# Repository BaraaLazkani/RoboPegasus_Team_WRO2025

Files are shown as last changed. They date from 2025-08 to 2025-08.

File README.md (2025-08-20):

## <center>RoboPegasus Team Report for WRO Future Engineers Category (2025)</center>
<p align="center">
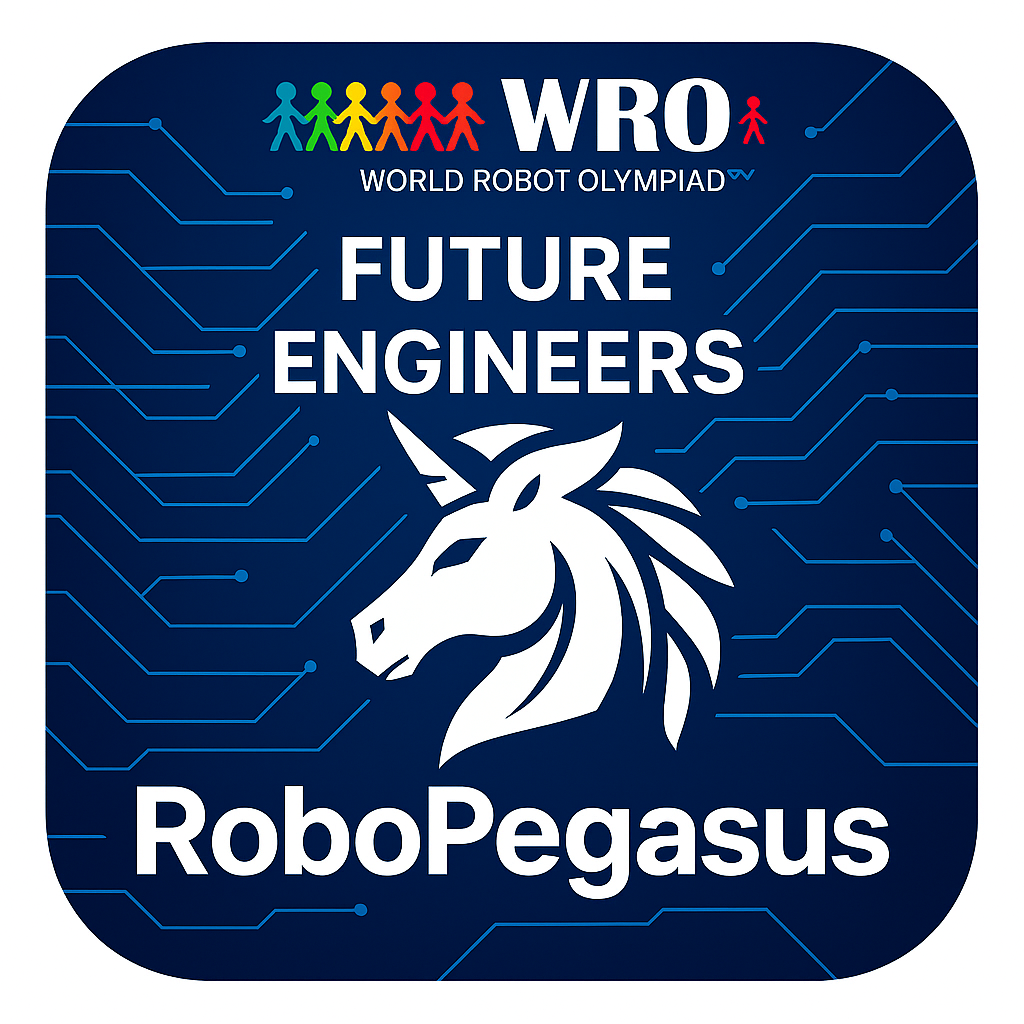
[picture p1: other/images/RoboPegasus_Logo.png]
WRO Logo
  
</p>

<p align="center">
  <strong>🏆 WRO Future Engineers 2025 Competition Entry</strong><br>
  Advanced Autonomous Navigation Robot
</p>

---

# 📋 Table of Contents

## 🚀 [Getting Started](#quick-start)
- [Repository Access & Requirements](#repository-access)
- [Video Demonstrations](#video-demonstrations)
- [Key Features Overview](#key-features)

## 📁 [Project Structure](#repository-structure)
- [Repository Organization](#file-organization)
- [Content Overview](#content-overview)

## 🔧 [Technical Documentation](#technical-documentation)

### ⚙️ [Robot Mechanisms](#robot-mechanisms)
- [Differential Gears](#differential-gears)
  - [Types of Differentials](#types-of-differentials)
  - [Benefits of Differential Gears](#benefits-of-differential-gears)
- [Ackermann Steering](#ackermann-steering)
  - [How It Works](#how-it-works)
  - [Main Purpose](#main-purpose)
- [Mechanism Integration](#fusion-between-differential-gears-and-ackermann-steering)
  - [Experiments Conducted](#experiments-conducted)
- [Implementation Details](#mechanisms-implementaion)
  - [Open Differential Implementation](#open-differential-implementation)
  - [Back Plexi Component](#1-back-plexi-component)
  - [Differential Replica](#2-differential-replica)
  - [Axis Component](#3-axis-component)
  - [Axis Holder](#4-axis-holder)
  - [Differential Holder](#5-differential-holder)
  - [Motor Holder](#6-motor-holder)
  - [Final Assembly](#6-final-assembly)
- [Ackermann Steering Implementation](#ackermann-steering-implementation)
  - [Original Kit Limitations](#original-kit-limitations-and-design-constraints)
  - [Custom Design Solution](#custom-plexi-glass-plate-design-and-manufacturing)
  - [Manufacturing Process](#manufacturing-process-and-quality-control)
  - [Performance Validation](#integration-benefits-and-performance-validation)

### 🚗 [Vehicle Design](#vehicle-main-body)
- [Main Body Design](#vehicle-main-body)
  - [Design Philosophy](#complete-from-scratch-design-philosophy)
  - [Manufacturing Techniques](#advanced-manufacturing-techniques)
  - [Precision Engineering](#precision-engineering-the-differential-challenge)
  - [Steering Integration](#ackermann-steering-integration)
- [Design Evolution](#evolution-through-iteration-learning-from-the-first-prototype)
  - [First Prototype Challenges](#first-prototype---design-challenges)
  - [Second Generation](#the-perfected-second-generation)
  - [Structural Redesign](#complete-structural-redesign)
  - [Power Management Revolution](#revolutionary-power-management-system)
- [Virtual Robot](#virtual-robot)
  - [CAD Modeling](#cad-design-and-modeling-philosophy)
  - [System Visualization](#complete-system-visualization)
  - [Architecture Design](#multi-tiered-architecture-design)
  - [Engineering Validation](#engineering-validation-through-virtual-modeling)
- [Design Lessons](#robots-design-lessons)

### 🏃 [Mobility Management](#mobility-management)
- [Motor Selection](#motor-selection-and-implementation)
  - [Drive Motor Specifications](#primary-drive-motor-jga25-370-245-rpm-dc-motor)
  - [Steering Actuator](#steering-actuator-mg996r-servo-motor)
  - [Control Implementation](#motor-control-implementation)
- [Chassis Design](#chassis-design-and-structural-implementation)
  - [Material Selection](#material-selection-and-structural-philosophy)
  - [Multi-Level Configuration](#multi-level-chassis-configuration)
  - [Component Integration](#component-integration-and-mounting-strategy)
- [Performance Analysis](#engineering-principles-and-performance-analysis)

### ⚡ [Power and Sense Management](#power-and-sense-management)
- [Battery System](#battery-specifications-and-power-analysis)
  - [Primary Power Source](#primary-power-source-zeee-li-poly-battery)
  - [Power Analysis](#power-consumption-analysis-and-runtime-calculations)
  - [Runtime Calculations](#component-power-consumption-summary)
- [Power Management System](#power-management-system-pms)
  - [Distribution Architecture](#custom-power-distribution-architecture)
  - [Star Topology](#star-topology-power-distribution)
- [Sensor Systems](#sensor-integration-and-selection-rationale)
  - [Ultrasonic Array](#ultrasonic-sensor-array-hc-sr04)
  - [Dynamic Positioning](#dynamic-sensor-positioning-sg90-servo-motors)
  - [Inertial Measurement](#inertial-measurement-mpu6050-imu)
  - [Infrared Detection](#infrared-detection-ir-sensor)
- [Processing Systems](#primary-processing-systems)
  - [Arduino Mega Implementation](#arduino-mega-2560-sensor-interface-and-control)
  - [Raspberry Pi Setup](#raspberry-pi-5-computer-vision-processing)

### 🚧 [Obstacle Management](#obstacle-management)
- [Open Challenge Algorithm](#autonomous-robot-navigation-algorithm-for-open-challenge)
  - [Algorithm Flow](#algorithm-flow)
  - [Algorithm Structure](#algorithm-structure)
  - [Control Parameters](#control-parameters)
  - [Mission Completion](#mission-completion-criteria)
- [Obstacle Challenge System](#obstacle-challenge-navigation-system)
  - [Startup Protocol](#startup-from-the-parking-lot)
  - [Directional Determination](#directional-determination-algorithm)
  - [CCW Navigation](#counter-clockwise-ccw-navigation-mode)
  - [CW Navigation](#clockwise-cw-navigation-mode)
  - [Corner Positioning](#corner-positioning-protocol)
  - [Pillar Navigation](#navigation-through-pillars)
- [Computer Vision](#pillar-color-detection-methodology)
  - [Detection Algorithm](#color-detection-algorithm)
  - [Pillar Classification](#pillar-configuration-classification)
  - [Error Handling](#error-handling-and-edge-cases)

## 👥 [Project Information](#project-information)
- [Team Contact](#team-contact)
  - [Team Members](#team-members)
  - [Contact Information](#contact-information)

---

## Quick Start

### Repository Access
**Important Note:** If accessing this GitHub repository from a restricted area, a VPN must be used for proper content display and functionality.

### Video Demonstrations
- **Open Challenge:** [Watch on YouTube (Coming Soon)](https://youtu.be/jW7eVu1ZF-4)
- **Obstacle Challenge:** [Watch on YouTube (Coming Soon)](https://youtu.be/LZvUotCrMSs)

### Key Features
- ✅ **Custom Differential Drive System** - From-scratch mechanical design
- ✅ **Ackermann Steering Integration** - Precision turning mechanics  
- ✅ **Advanced Sensor Array** - 7 ultrasonic sensors + IMU + camera
- ✅ **Dual-Processor Architecture** - Arduino Mega + Raspberry Pi 5
- ✅ **Professional Power Management** - Custom PMS with star topology
- ✅ **Computer Vision** - Real-time pillar detection and classification
- ✅ **Autonomous Navigation** - Multi-algorithm approach for different challenges

---

## Repository Structure

### File Organization
```
📦 RoboPegasus-WRO-2025/
├── 📁 t-photos/           # Team photos (official + fun)
├── 📁 v-photos/           # Vehicle photos (6 angles + generations) and Virtual Robot Photos
│   ├── 📁 First_Generation_Robot (Not Used)/
│   └── 📁 Second_Generation_Robot (Used in Competition)/
├── 📁 video/              # Video demonstrations and links
├── 📁 schemes/            # Electrical schematics and diagrams
├── 📁 src/                # Source code for all components
├── 📁 models/             # 3D printed and laser cut parts
├── 📁 other/              # Additional resources
│   ├── 📁 images/         # Documentation images
│   ├── 📁 files/          # Simulation and instruction files
│   └── 📁 gif files/      # Algorithm demonstration GIFs
├── 📄 README.md           # This comprehensive documentation
├── 📄 LICENSE             # Project license
```

### Content Overview
This repository represents RoboPegasus team's complete engineering solution for the WRO Future Engineers Category competition in 2025. It includes all necessary documentation, code, models, and materials used in the design, construction, and programming of our autonomous robot.

Our focus has been on creating a robust and efficient vehicle capable of navigating complex tracks with obstacles, adhering to competition rules, and demonstrating advanced engineering skills through innovative mechanical design and sophisticated software algorithms.

---

# Technical Documentation

# Robot Mechanisms

In self-driving cars, the most important aspect is their mechanical mechanisms, which ensure smooth and safe operation. Our design incorporates differential gears for the Rear-Wheel Drive (RWD) system, providing balance and control during turns. For steering, we utilize a Ackermann Steering mechanism, which offers precise control and reliability.

## Differential Gears

Differential gears play a crucial role in automotive engineering. They allow the wheels on a vehicle to rotate at different speeds, particularly when the car is turning. This functionality is vital because the inner wheels travel a shorter distance than the outer wheels during a turn.

The following **HTML** file simulates how Differential Gears work:
- [Differential Gears Simulation](other\files\differential_simulation.html)

**Note:** You will have to download the file and open it using your prefferd browser to access the simulation.

### Types of Differentials

1. **Open Differential**: is the most common type, found in many non-performance vehicles. It is simple and cost-effective but can transfer torque to a wheel without traction, causing it to spin uselessly.

<p align="center">
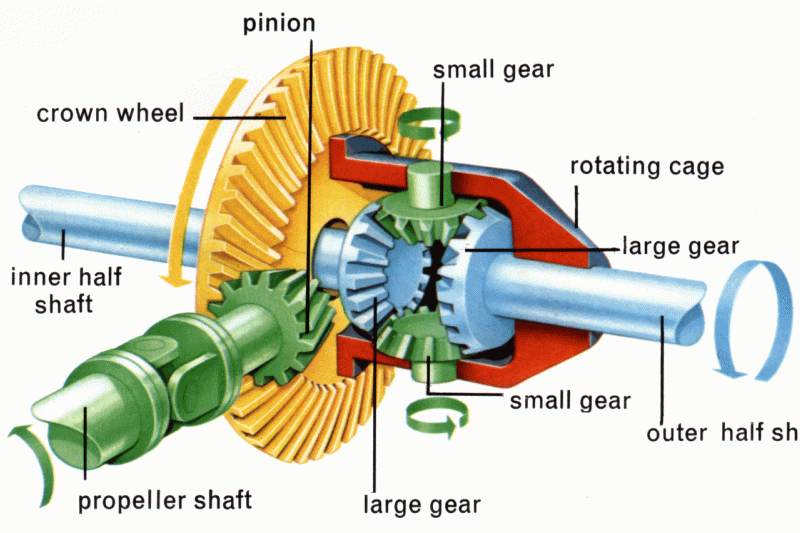
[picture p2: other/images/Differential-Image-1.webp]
Open Differential
  
</p>

2. **Locking Differential**: Often used in off-road vehicles, this type can lock the wheels to spin at the same speed, providing better traction on uneven surfaces.

<p align="center">
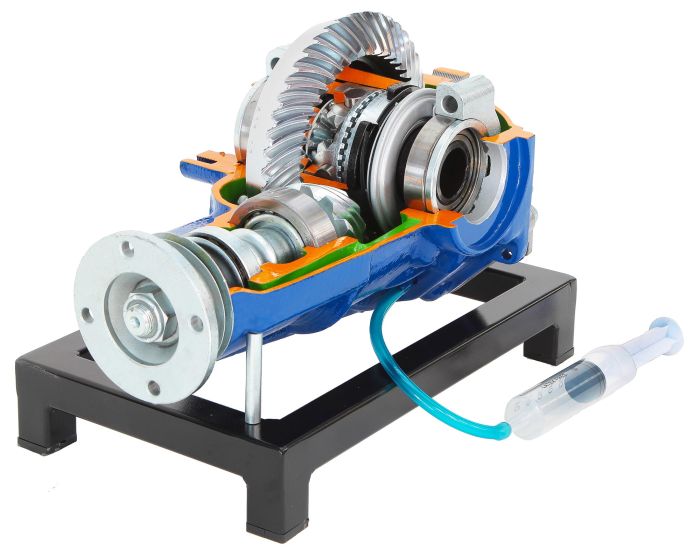
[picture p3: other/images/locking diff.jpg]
Locking Differential
  
</p>

3. **Limited-Slip Differential (LSD)**: Combines features of both open and locking differentials, allowing wheels to spin at different speeds but can transfer more torque to the wheel with better traction.

<p align="center">
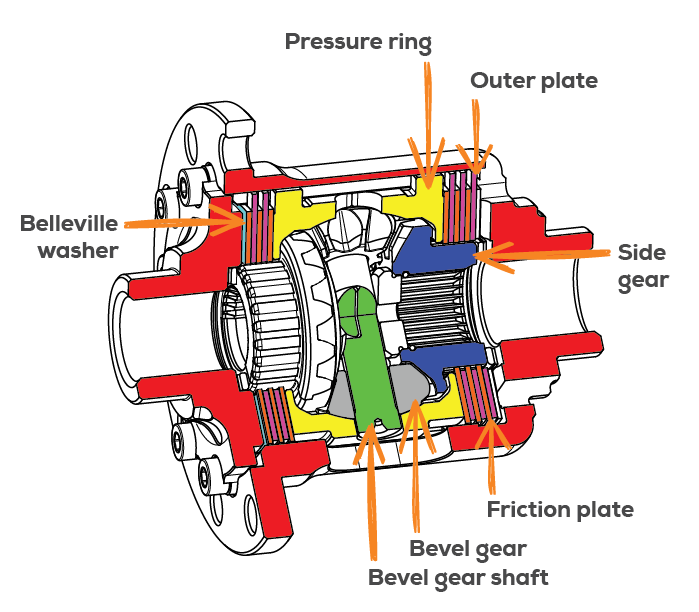
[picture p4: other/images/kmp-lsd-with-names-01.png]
Limited-Slip Differential
  
</p>

### Benefits of Differential Gears

- **Improved Handling**: Differentials enhance vehicle handling, especially around corners, by allowing wheels to rotate at appropriate speeds.
- **Increased Traction**: Locking and limited-slip differentials provide better traction on slippery or uneven surfaces.
- **Enhanced Stability**: They improve stability by distributing power evenly to the wheels, preventing loss of control.

## Ackermann Steering

The following **HTML** file simulates how Ackermann Steering Mechanism work:
- [Ackermann Steering Mechanism Simulation](other\files\ackermann_steering_sim.html)  

**Note:** You will have to download the file and open it using your prefferd browser to access the simulation.

<p align="center">
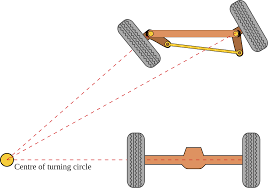
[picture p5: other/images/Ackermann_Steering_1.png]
Ackermann_Steering_1
  
</p>

Ackermann Steering is a geometric arrangement of linkages in the steering system of a vehicle designed to avoid the problem of tire slipping during turns. Its primary goal is to ensure that all wheels of a vehicle follow concentric circular paths with different radiuses, which allows for smoother and more efficient turning.

### How It Works:
- When a vehicle turns, the inner and outer front wheels trace different arcs. The inner wheel needs to turn at a sharper angle than the outer wheel.
- The Ackermann steering geometry links the steering arms such that the front wheels pivot about different angles, aligning with their respective turning circles.
- This prevents tire scrubbing, reduces wear, and improves handling and safety.
<p align="center"> 
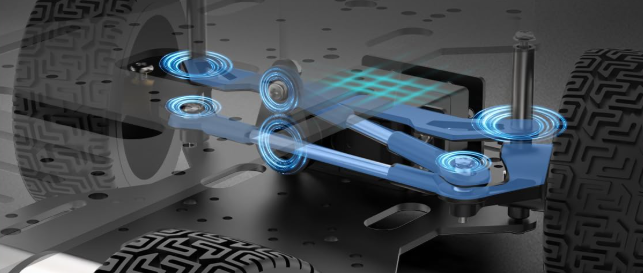
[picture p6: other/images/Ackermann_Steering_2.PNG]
original_vs_custom_comparison
   
</p>

### Main Purpose:
- **Reduce Tire Slippage:** By ensuring the wheels roll along the correct turning paths without lateral slipping.
- **Improve Steering Accuracy:** Helps vehicles maintain better control, especially during sharp turns.
- **Enhance Safety:** Precise steering response reduces the risk of skidding or losing control.
- **Increase Efficiency:** Minimizes energy loss from friction and tire wear, improving fuel economy and tire lifespan.

## Fusion Between Differential Gears and Ackermann Steering

After extensive experimentation and careful analysis, we found that combining Ackermann steering with differential gears provides the best control and maneuverability for our robot.

### Experiments Conducted:

- **Experiment 1: Using Only Differential Gears**  
  We tested relying solely on differential gears and Direct-Acting Steering for turning. While the robot could perform basic turns, it struggled with precise cornering and exhibited excessive tire slippage on sharp curves.

<p align="center"> 
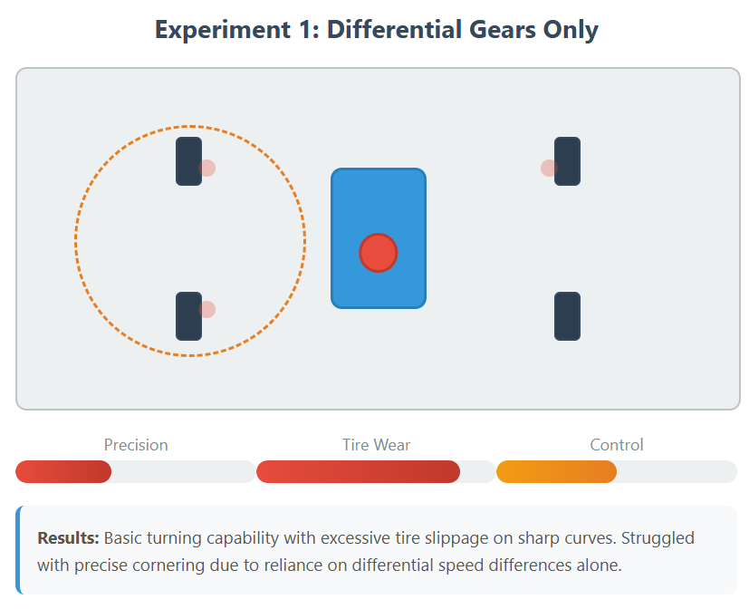
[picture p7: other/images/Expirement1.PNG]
Expirement 1
   
</p>
<p align="center"> 
  Expirement 1 
</p>

- **Experiment 2: Using Only Ackermann Steering**  
  Implementing only Ackermann steering improved turning accuracy and reduced tire wear. However, the robot experienced difficulty in handling uneven terrain and maintaining smooth speed control during turns.

<p align="center"> 
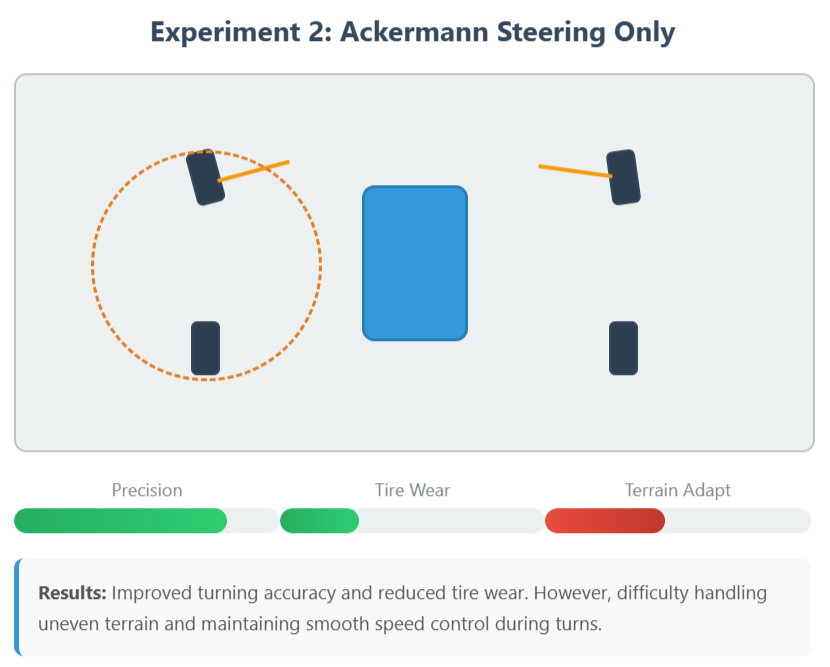
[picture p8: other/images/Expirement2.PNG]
Expirement 2
   
</p>
<p align="center"> 
  Expirement 1 
</p>

- **Experiment 3: Combining Ackermann Steering with Differential Gears**  
  By integrating differential gears with Ackermann steering, the robot achieved smooth and precise turning, excellent traction, and better adaptation to various surfaces. This fusion allowed us to minimize wheel slippage and maximize responsiveness, providing superior overall control.

<p align="center"> 
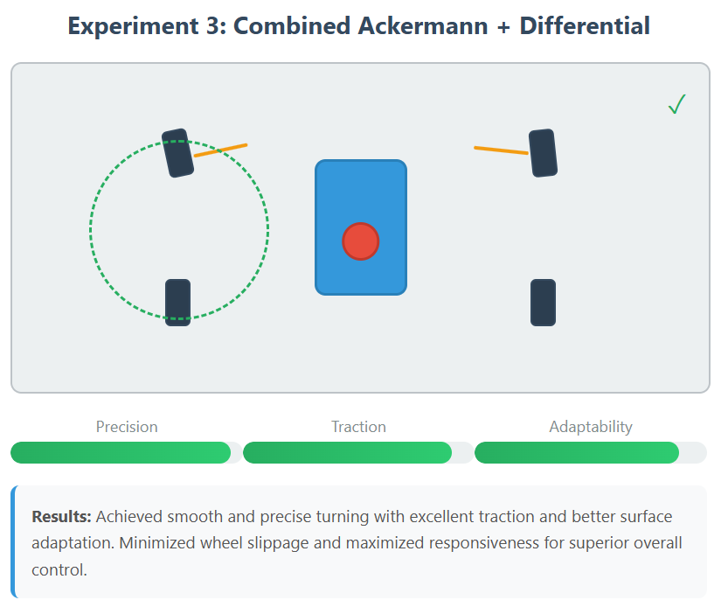
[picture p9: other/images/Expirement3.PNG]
Expirement 3
   
</p>
<p align="center"> 
  Expirement 1 
</p>

## Mechanisms Implementaion

### Open Differential Implementation

We opted to implement an **open differential** in our robot’s drivetrain due to its mechanical simplicity, reliability, and suitability for our performance requirements. An open differential is sufficient for evenly distributing torque between the driven wheels while allowing them to rotate at different speeds during turns, thereby reducing tire wear and improving handling.  

To achieve this, we sourced a **metal open differential unit** for its durability and consistent performance. The primary challenge was integrating it into our custom chassis with precise alignment. The differential housing and its associated axles—both of which were **3D printed**—needed to be positioned with millimeter-level accuracy to ensure optimal functionality, minimize friction losses, and maintain structural stability under load.  

The following images illustrate the detailed design of the mechanism, highlighting the placement of the differential, the geometry of the printed axles, and the surrounding support structures. Since a CAD model for the purchased differential gears was unavailable, we created a custom simulation in SolidWorks, which successfully replicated the intended mechanical behavior. These visuals also serve as **step-by-step assembly instructions**, guiding the exact positioning and fastening methods to accurately replicate the build.

**Important Note:** There are **HTML** and **PDF** files that provide full building instructions.  
You can access them here:  

- [Building Instructions (HTML)](other/files/Differential%20Gears%20Mechanism%20Assembly%20Instructions.html)  
- [Building Instructions (PDF)](other/files/Differential%20Gears%20Mechanism%20Assembly%20Instructions.pdf)  

**Note:** You will have to download the files and open them using your prefferd browser.

#### 1. Back Plexi Component  

##### 1.1 Design Overview  

<p align="center"> 
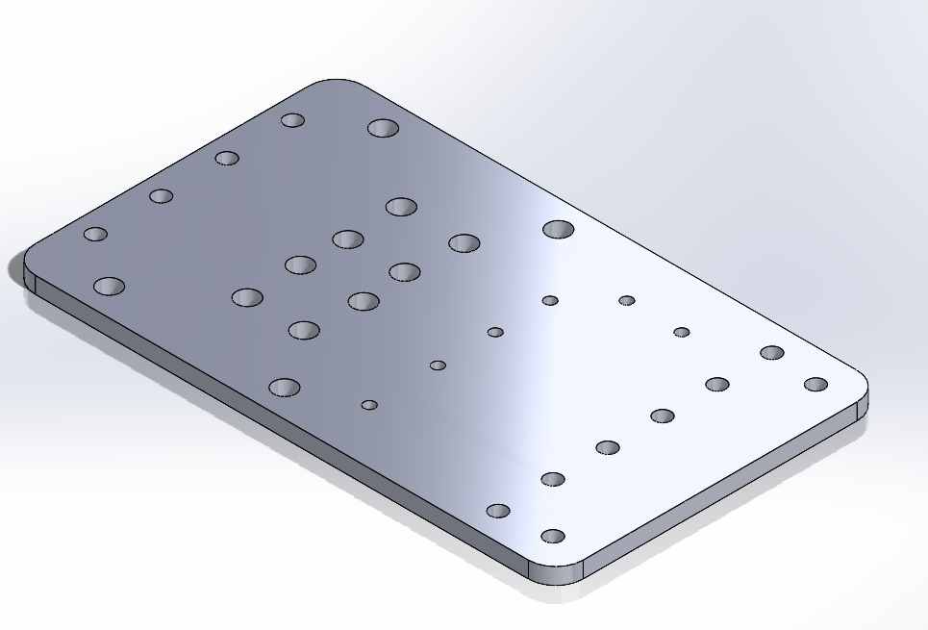
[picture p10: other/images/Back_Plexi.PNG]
Back Plexi
   
</p>  

##### 1.2 Design Rationale  

The Back Plexi component functions as the primary support structure for the entire rear-wheel-drive (RWD) mechanism. Its design is guided by several key engineering considerations:  

- **Material Selection**: Constructed from 3 mm-thick plexiglass, providing sufficient strength and rigidity to support the robot’s weight while maintaining a lightweight profile.  
- **Structural Configuration**: Designed with precisely positioned openings to accommodate all subsequent components, as well as mounting holes for secure attachment to the front plexi panel.  
- **Integration Strategy**: Positioned slightly lower than the front plexi to facilitate improved maneuverability, particularly during turning operations.  

---

#### 2. Differential Replica  

##### 2.1 Design Overview  

<p align="center"> 
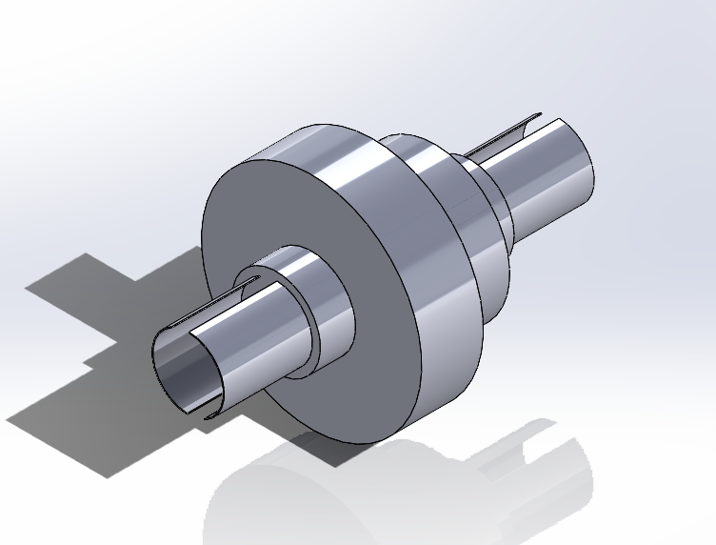
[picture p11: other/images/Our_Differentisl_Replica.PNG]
Differential Replica
  
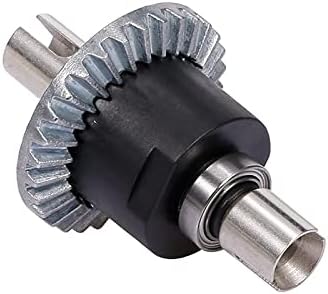
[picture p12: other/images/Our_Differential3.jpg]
    
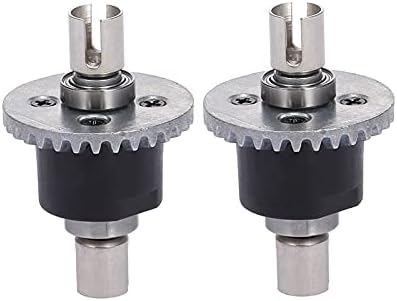
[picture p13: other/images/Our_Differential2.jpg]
   
</p>  

##### 2.2 Design Rationale  

The differential replica component was engineered to accurately reproduce the functionality and geometry of the original system while accommodating project-specific requirements:  

- **Mechanical Functionality**: Designed to faithfully replicate the torque distribution and rotational behavior of the original open differential, ensuring realistic performance in the rear-wheel-drive mechanism.  
- **Scale Considerations**: Manufactured at a 1:1 scale with the original differential to guarantee dimensional consistency and maintain the correct spatial relationships between interconnected components.  
- **Performance Requirements**: Built to sustain the same operational loads, rotational speeds, and torque handling capacity as the original, enabling reliable performance during testing and operation.  
- **Compatibility**: Precisely matched to the original dimensions so that all related parts—including the axles, gears, and mounting structures—could be designed and fabricated without the need for later adjustments.  

##### 2.3 Engineering Tricks and Innovations  

To ensure full compatibility with the rest of the system, the replica was reverse-engineered with exact dimensional accuracy down to the smallest detail. This precision was critical because the design of subsequent components—such as the axle supports, gear housings, and mounting plates—was entirely dependent on the differential’s geometry. Any deviation, even minor, would have caused misalignment and compromised the mechanical performance, so high-precision fabrication and repeated verification measurements were employed throughout the process.  

---

#### 3. Axis Component

##### 3.1 Design Overview  

<p align="center">
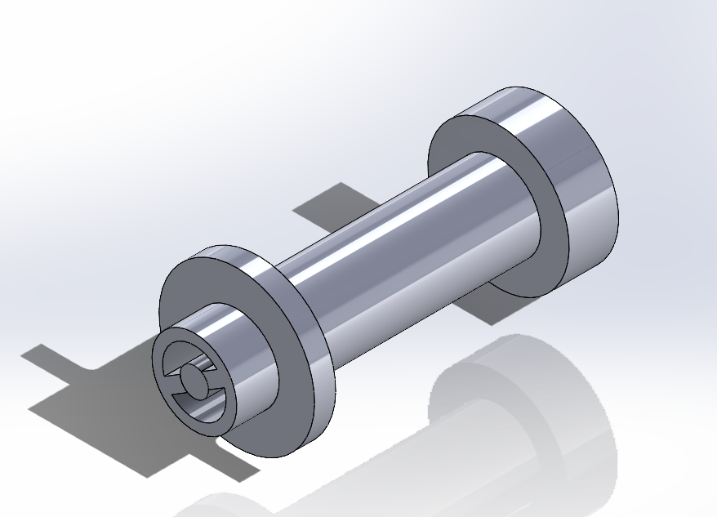
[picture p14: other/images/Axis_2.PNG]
  
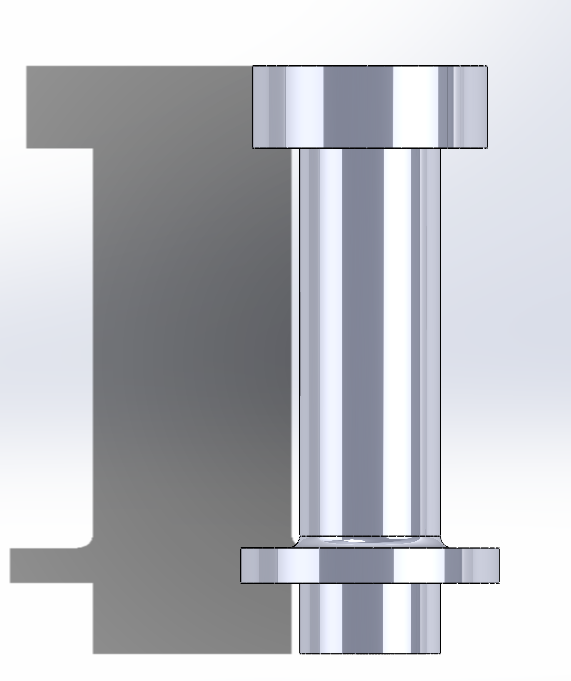
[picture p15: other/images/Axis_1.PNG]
  
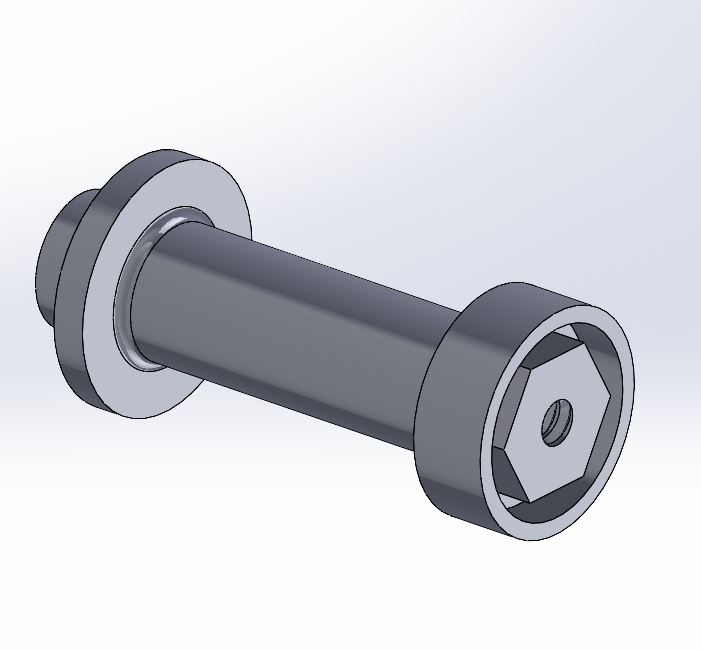
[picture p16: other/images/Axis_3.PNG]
  
</p>  

##### 3.2 Design Rationale  

The axis component serves as the primary rotating shaft, transmitting motion and torque between the differential and the wheels. Its design required meticulous attention to several critical factors:  

- **Load Distribution**: Engineered to evenly transmit forces from the wheel to the differential, ensuring balanced torque delivery and minimizing bending stress during operation.  
- **Rotational Mechanics**: Precisely machined to interface seamlessly with bearings and the differential housing, enabling smooth, low-friction rotation under load.  
- **Material Properties**: Fabricated from a high-strength, wear-resistant material to withstand repeated torsional and shear stresses without deformation.  
- **Precision Requirements**: Manufactured with strict dimensional tolerances to guarantee perfect alignment and eliminate axial play, ensuring consistent performance over time.  

##### 3.3 Critical Precision Features and Innovations  

A defining feature of this axis is its **exactly calculated length**, determined to achieve a perfect fit between the differential on one side and the wheel assembly on the other. This precision is crucial—any deviation could cause misalignment, impair torque transfer, or create mechanical interference with surrounding components.  

Additionally, a **retaining ring** is strategically positioned along the shaft to prevent any lateral movement, locking the axis firmly in its operational position. This seemingly simple element plays an essential role in maintaining the stability and geometry of the drivetrain, preventing even millimeter-scale shifts that could disrupt the overall performance of the robot. The combination of these precision-driven design choices ensures the axis operates as a stable, reliable, and indispensable link within the system.  

---

#### 4. Axis Holder  

##### 4.1 Design Overview  

<p align="center"> 
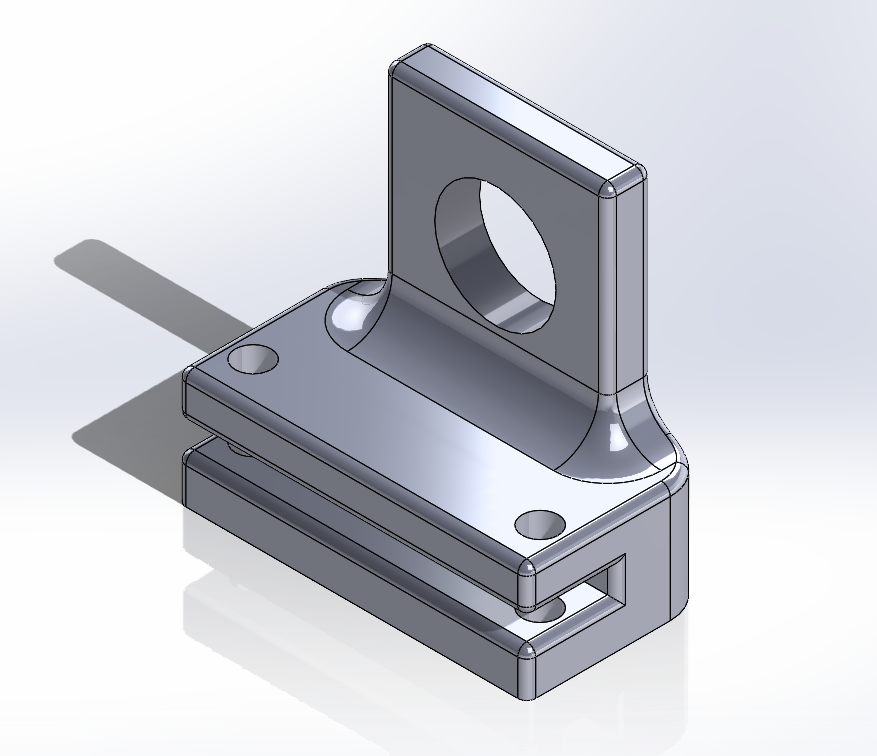
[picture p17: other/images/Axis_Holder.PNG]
Axis Holder
   
</p>  

##### 4.2 Design Rationale  

The axis holder serves as a critical structural element, ensuring both secure positioning and smooth operation of the axis assembly. Its design addresses the following engineering considerations:  

- **Structural Integrity**: Designed to bear the combined operational loads transmitted through the axis, including torque, radial forces, and minor bending stresses, without deformation or displacement.  
- **Alignment Precision**: Precisely machined to maintain the axis in perfect alignment with the differential and wheel assembly, preventing angular misalignment that could lead to uneven wear or mechanical inefficiency.  
- **Assembly Considerations**: Strategically located at the end of the plexi panel to simplify installation and allow straightforward access for maintenance, replacement, or lubrication of internal components.  
- **Vibration Control**: Incorporates a stable mounting interface to reduce unwanted vibrations, enhancing both operational smoothness and component lifespan.  

##### 4.3 Precision Integration and Retention Mechanism  

A key feature of the axis holder is the **precision-machined central bore** designed to house a rollman (ball bearing). This ensures low-friction, stable rotation of the axis while supporting the operational loads. The holder’s placement at the plexi panel’s edge allows optimal positioning for both structural support and drivetrain alignment.  

The previously discussed **retaining ring on the axis** works in direct coordination with this holder, preventing any axial movement and firmly locking the shaft in place during operation. This interaction between the holder, bearing, and retaining ring is essential for maintaining drivetrain stability, ensuring consistent torque transfer, and preventing even minor positional shifts that could compromise the mechanical system’s performance.  

---

#### 5. Differential Holder  

##### 5.1 Design Overview  

<p align="center"> 
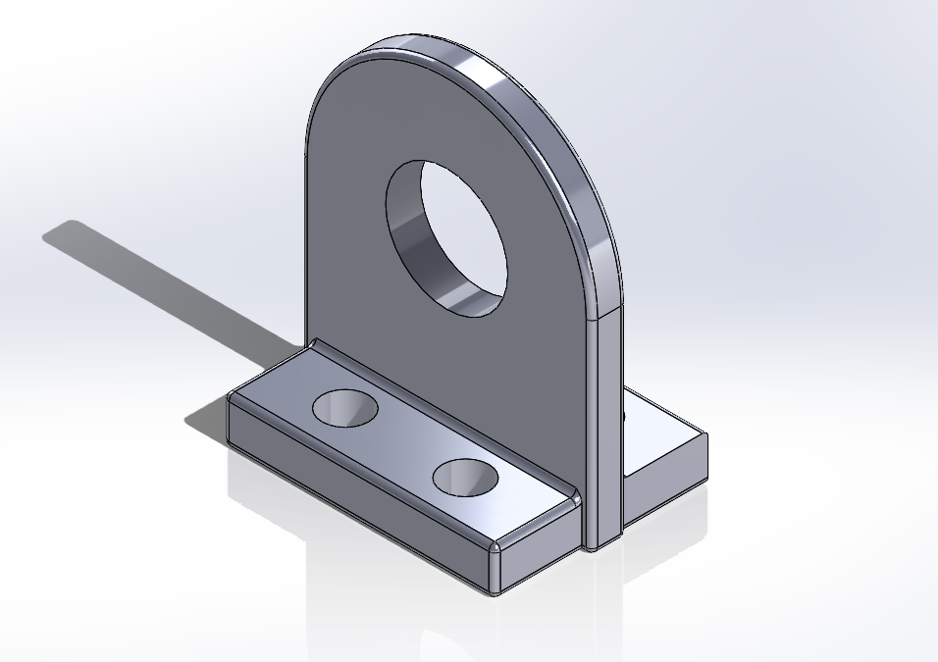
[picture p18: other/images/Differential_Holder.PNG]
Differential Holder
   
</p>  

##### 5.2 Design Rationale  

The differential holder is designed to securely mount the differential replica onto the back plexi, ensuring stable positioning and reliable drivetrain operation. The design addresses the following key considerations:  

- **Mounting Strategy**: Provides a rigid and stable interface between the differential housing and the back plexi, preventing vertical displacement during operation.  
- **Spatial Constraints**: Accommodates the limited clearance around the differential, ensuring that mounting points do not interfere with rotating components or obstruct adjacent parts.  
- **Thermal Considerations**: While heat generation in this configuration is minimal, the open structure allows sufficient airflow around the differential for passive cooling.  
- **Maintenance Access**: Designed to allow convenient access for fine adjustments, lubrication, and inspection without requiring full disassembly of the drivetrain.  

##### 5.3 Critical Positioning and Precision Adjustments  

While previous components ensured that the differential and its axis could not shift laterally, the **differential holder** plays the crucial role of locking its vertical position relative to the back plexi. This prevents the assembly from moving up or down, maintaining correct gear engagement and drivetrain geometry.  

A significant challenge in this design was the **extremely thin non-rotating sections** of the differential housing, which allowed almost no margin for error. Even a **1 mm misalignment** would have rendered the mechanism inoperable. As a result, the mounting points and holder geometry were repeatedly adjusted and fine-tuned until the perfect position was achieved. This iterative precision-fitting process was essential to ensure flawless meshing of gears, stable torque transfer, and smooth overall performance.  

---

#### 6. Motor Holder  

##### 6.1 Design Overview  

<p align="center"> 
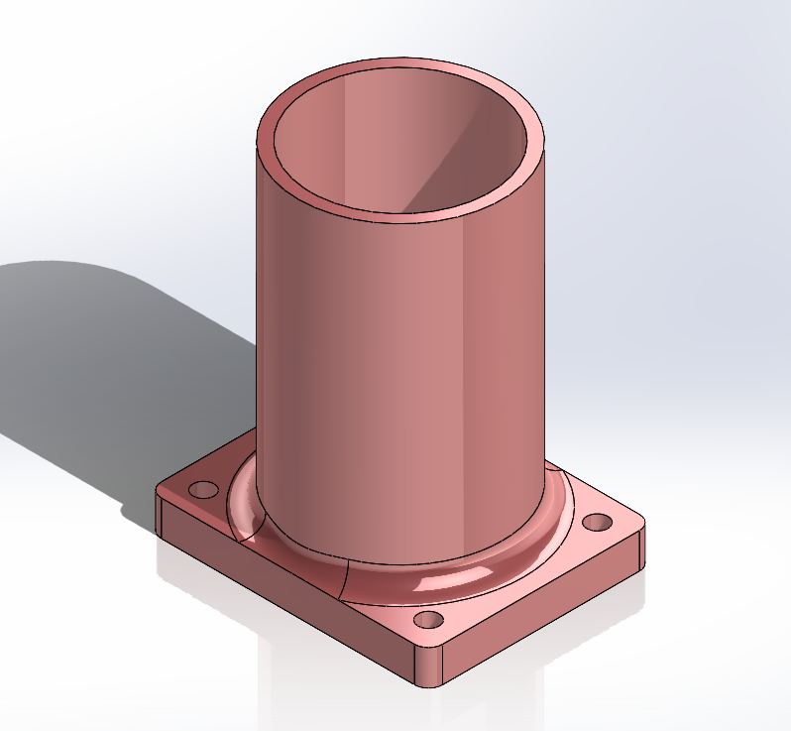
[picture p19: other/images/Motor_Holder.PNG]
Motor Holder
  
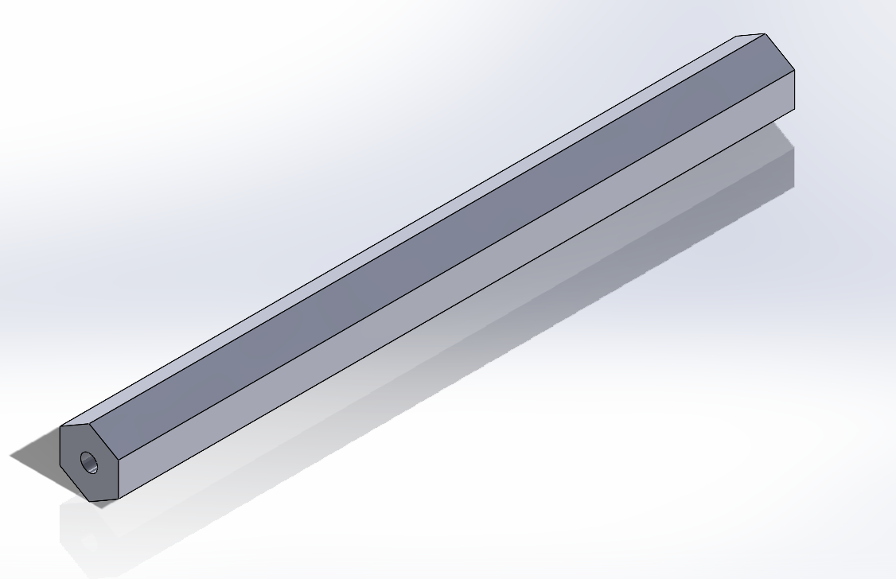
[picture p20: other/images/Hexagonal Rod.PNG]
Hexagonal Rod
    
</p>  

##### 6.2 Design Rationale  

The motor holder is designed to firmly secure the drive motor while ensuring optimal positioning for efficient power transmission to the drivetrain. Key engineering considerations include:  

- **Vibration Isolation**: Provides a stable mounting interface that minimizes vibrations transferred from the motor to the chassis, reducing mechanical noise and protecting other components from wear.  
- **Thermal Management**: Ensures adequate spacing and exposure for natural heat dissipation from the motor casing, preventing overheating during extended operation.  
- **Electrical Integration**: Designed with sufficient clearance and routing space for power leads and control wires, enabling safe and organized electrical connections.  
- **Adjustability**: Allows fine-tuning of the motor’s position to achieve optimal gear meshing and torque transfer efficiency.  

##### 6.3 Adaptive Positioning and Height Adjustment Innovations  

One of the primary challenges in designing the motor holder was determining the **precise positioning** required for perfect gear engagement, ensuring the motor’s rotational power was transferred efficiently to the wheels. To address this, instead of relying on a single fixed mounting hole in the plexi, we implemented a **slotted track** system. This design enables real-world adjustment of the motor’s position until the ideal gear alignment is achieved.  

The second challenge was setting the **exact height** of the motor holder. This was solved by fabricating **custom hexagonal spacer rods** in varying heights, which could be stacked or combined to achieve the precise elevation required. This modular height-adjustment system allowed for rapid experimentation and fine-tuning, ensuring the motor remained perfectly aligned with the drivetrain under operational loads.  

---

#### 6. Final Assembly  

Once all the above components have been fabricated—either by 3D printing, laser cutting, or other manufacturing methods—and compatible tires have been sourced (or custom-designed, if resources allow), the complete rear-wheel-drive (RWD) mechanism can be assembled.  

The assembly process involves integrating each precisely engineered part in the sequence described above, ensuring all tolerances, alignments, and positional adjustments are maintained for optimal performance. The result is a fully functional RWD system capable of delivering smooth and efficient power transmission from the motor to the wheels.  

The following image illustrates the fully assembled mechanism:  

<p align="center">
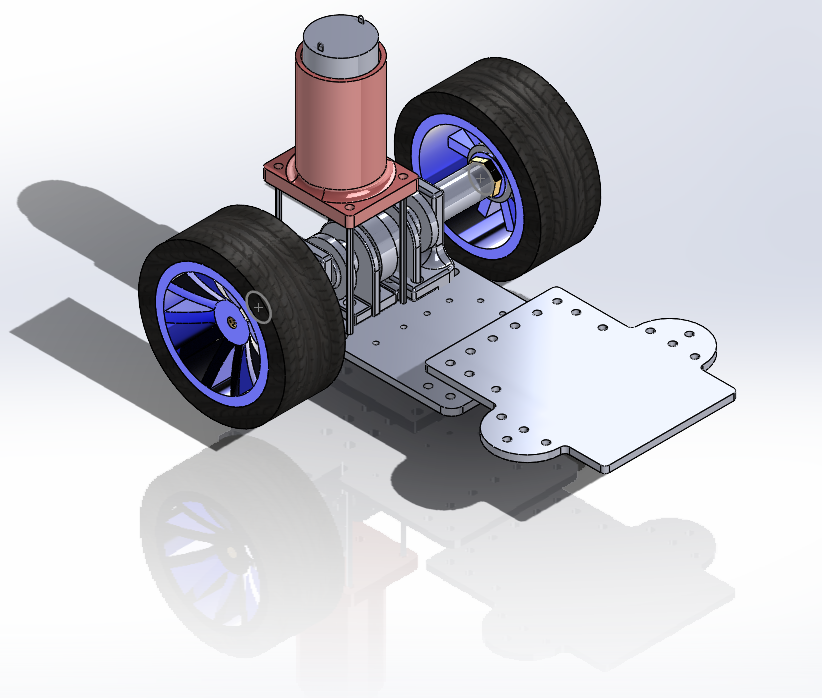
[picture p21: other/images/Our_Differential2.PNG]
Assembled RWD Mechanism
  
</p>  

---

### Ackermann Steering Implementation

The implementation of the Ackermann steering mechanism in our robot required significant customization and adaptation to meet our specific dimensional constraints and design requirements. While we adopted the proven Ackermann steering geometry from an existing 4WD chassis kit, the direct integration of the original components was not feasible due to fundamental dimensional incompatibilities with our compact robot design.

#### Original Kit Limitations and Design Constraints

The original Ackermann steering kit featured a chassis platform measuring approximately 24 centimeters in length, which significantly exceeded our target robot dimensions of 16-18 centimeters. This dimensional discrepancy presented a critical design challenge: how to retain the precise geometric relationships essential for proper Ackermann steering function while adapting the mechanism to our substantially more compact platform.

The original kit's plexi-glass (acrylic) mounting plate contained all the necessary mounting holes, pivot points, and structural elements required for the steering mechanism's operation. However, the extensive length of this component made direct implementation impossible within our size constraints. Simply scaling down the entire mechanism would have compromised the steering geometry and potentially introduced mechanical interference issues with other robot subsystems.

#### Custom Plexi-Glass Plate Design and Manufacturing

To address this challenge, we developed a custom plexi-glass mounting plate that retained the critical geometric elements of the original design while conforming to our compact robot architecture. Our approach involved a detailed analysis of the original mounting plate to identify the essential features required for proper Ackermann steering function.

**Critical Feature Identification**: We conducted a comprehensive examination of the original plate to identify which mounting holes, pivot points, and structural elements were absolutely necessary for steering mechanism operation. This analysis revealed that only the forward section of the original plate contained the crucial mounting points for the steering servo, tie rods, and wheel hub assemblies.

**Precision Replication**: Using advanced CAD modeling, we created a precise replica of the essential forward section of the original mounting plate. This involved exact measurement of hole diameters, center-to-center spacing, and angular relationships to ensure that the steering geometry would remain unchanged despite the dimensional reduction.

**Custom Integration Design**: Beyond simply replicating the necessary holes, we designed the remaining portions of the custom plate to integrate seamlessly with our robot's overall architecture. This included provisions for mounting points that align with our chassis structure, clearance cutouts for other subsystems, and optimized material usage to minimize weight while maintaining structural integrity.

#### Manufacturing Process and Quality Control

The custom plexi-glass plate was manufactured using precision laser cutting technology to ensure dimensional accuracy and clean, professional edges. The laser cutting process provided several critical advantages: it delivered the precise hole diameters required for proper mechanical fit, maintained exact center-to-center spacing to preserve steering geometry, produced clean edges that required no post-processing, and ensured consistent material properties throughout the component.

Quality control measures included dimensional verification of all critical features using precision measuring instruments, test fitting with original steering components to confirm compatibility, and structural integrity testing to ensure the reduced-size plate could withstand operational loads.

#### Comparative Analysis: Original vs. Custom Design

The following images demonstrate the significant dimensional differences between the original kit component and our custom-designed solution:

<p align="center"> 
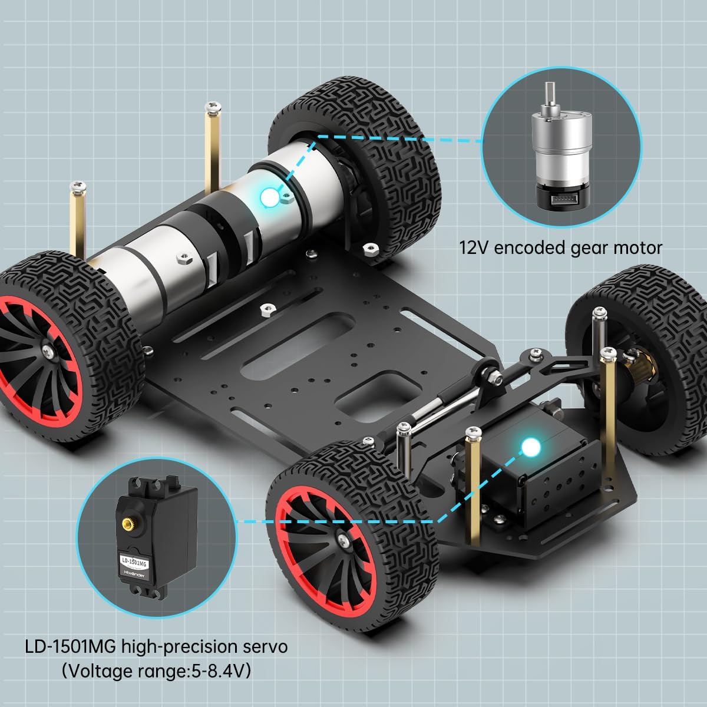
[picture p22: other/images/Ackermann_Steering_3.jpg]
original_ackermann_kit_plate
   
</p>

<p align="center"> 
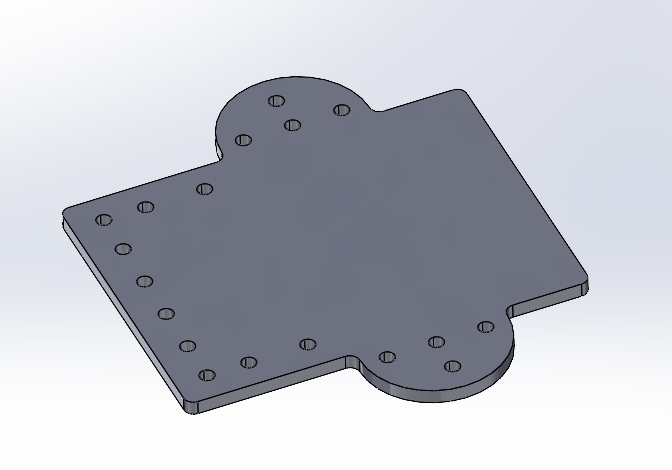
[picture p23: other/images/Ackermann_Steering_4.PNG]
custom_ackermann_plate
   
</p>

The comparison clearly illustrates how our custom design maintains the critical mounting hole pattern and geometric relationships while eliminating unnecessary material and adapting the overall shape to complement our robot's architecture. The custom plate measures approximately 30% less in overall length while preserving 100% of the functional mounting points required for proper Ackermann steering operation.

#### Integration Benefits and Performance Validation

Our custom Ackermann steering implementation delivers several significant advantages over attempting to modify or adapt the original kit components:

**Optimal Size Integration**: The custom plate dimensions perfectly complement our compact robot design, eliminating wasted space and reducing overall system weight.

**Preserved Steering Geometry**: By maintaining exact hole spacing and angular relationships, we ensured that the Ackermann steering principle operates exactly as intended, with proper wheel angle coordination during turns.

**Enhanced Structural Efficiency**: The custom design eliminates unnecessary material while maintaining structural integrity, resulting in improved weight distribution and reduced rotational inertia.

**Seamless System Integration**: The tailored design allows for optimal integration with other robot subsystems, avoiding mechanical interference and simplifying overall assembly processes.

Performance validation confirmed that our custom Ackermann steering implementation performs identically to the original kit design while providing superior integration characteristics for our specific application. The steering response is smooth and precise, with proper coordination between inner and outer wheel angles during turning maneuvers, validating our approach of preserving critical geometric relationships while adapting overall dimensions to our design requirements.

## Vehicle Main Body

### Complete From-Scratch Design Philosophy

Our robot represents a testament to engineering excellence and meticulous design precision. Every single component, mechanism, and structural element was conceived, designed, and implemented entirely from scratch by our team. This wasn't a modification of existing platforms or an assembly of pre-made components – it was a ground-up engineering endeavor that demanded months of careful consideration, precise calculations, and iterative refinement.

The design process spanned approximately two months of intensive development, driven by our unwavering commitment to perfection. We refused to compromise on any aspect of the design, ensuring that every element served a specific purpose and contributed to the overall system's efficiency and reliability. Every measurement was calculated with precision, every joint was analyzed for optimal stress distribution, and every component placement was strategically determined to maximize functionality while maintaining structural integrity.

### Advanced Manufacturing Techniques

The construction of our robot employed state-of-the-art manufacturing methods, combining the precision of 3D printing technology with the accuracy of laser cutting systems. The majority of structural components were meticulously 3D printed using high-strength materials, allowing us to achieve complex geometries and intricate internal structures that would be impossible with traditional manufacturing methods. Critical components requiring exceptional precision and smooth surfaces were fabricated using laser cutting technology, ensuring perfect dimensional accuracy and clean, professional edges.

This hybrid manufacturing approach enabled us to optimize each component for its specific function – using 3D printing for complex mechanical assemblies and internal structures, while employing laser cutting for precision panels, mounting brackets, and interface components. The result is a robot that showcases the best of both manufacturing worlds, with each part perfectly suited to its role in the overall system.

### Precision Engineering: The Differential Challenge

Our commitment to precision engineering is perhaps best exemplified by our approach to the differential gear mechanism. During the initial design phase, we encountered a critical tolerance issue where the gear clearances were calculated to within 1 millimeter precision. Upon detailed analysis and testing, we discovered that this minimal clearance was insufficient for optimal performance and long-term reliability. Rather than accepting a suboptimal solution, we completely redesigned this crucial mechanism, recalculating all dimensions, gear ratios, and clearances to achieve perfect mechanical harmony.

This redesign process involved extensive CAD modeling, stress analysis, and multiple prototype iterations. We analyzed the torque distribution, backlash requirements, and thermal expansion considerations to ensure that the differential system would perform flawlessly under all operating conditions. The final design represents hundreds of hours of engineering refinement, resulting in a differential mechanism that operates with exceptional smoothness and precision.

### Ackermann Steering Integration

While our robot is predominantly an original design, we made one strategic decision to incorporate proven technology where it made engineering sense. The Ackermann steering system is the sole component adapted from an existing 4WD Ackermann chassis design. However, this wasn't a simple plug-and-play integration – we carefully analyzed the steering geometry, modified the mounting points, and seamlessly integrated it into our custom chassis design.

The Ackermann steering principle ensures that during turns, the inner wheel follows a tighter radius than the outer wheel, eliminating tire scrubbing and providing smooth, efficient steering. By incorporating this time-tested mechanism into our original design, we maintained our commitment to performance while leveraging established engineering principles where they provided clear advantages.

### Evolution Through Iteration: Learning from the First Prototype

Our current robot represents the second complete iteration of our design, born from the valuable lessons learned during our first prototype's development and testing phase. The original robot, while functional, revealed several critical design flaws that demanded a complete redesign approach.

### First Prototype - Design Challenges

<p align="center">
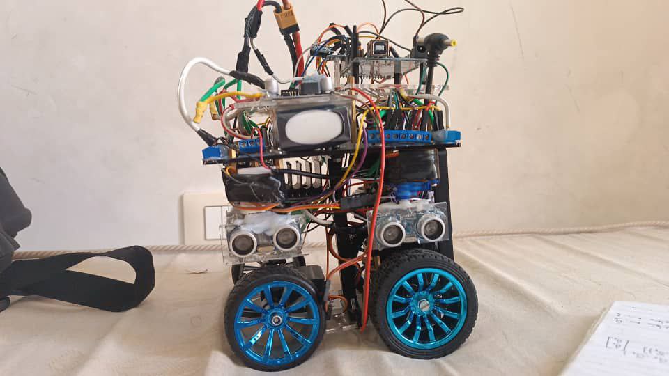
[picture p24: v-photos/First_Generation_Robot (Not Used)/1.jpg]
  
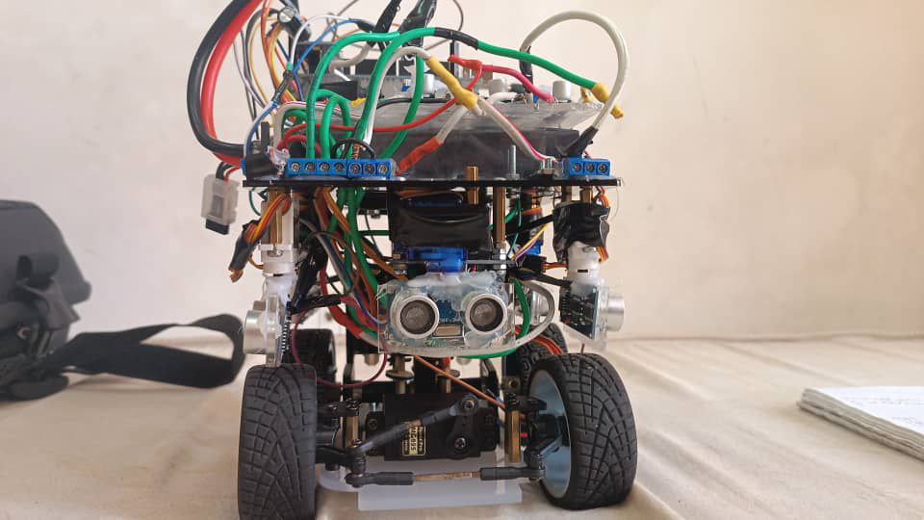
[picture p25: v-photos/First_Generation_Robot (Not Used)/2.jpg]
  
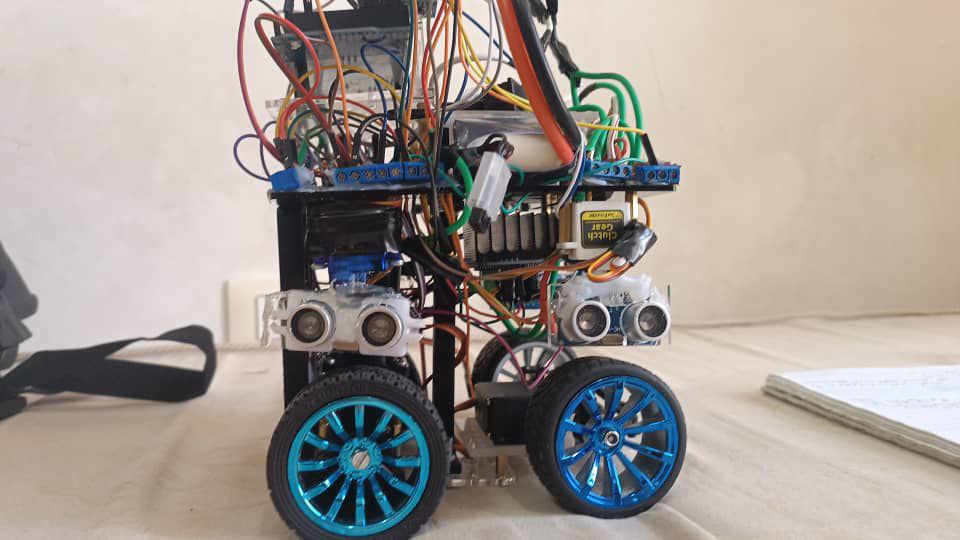
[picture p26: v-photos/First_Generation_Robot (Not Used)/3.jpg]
  
</p>

The first iteration, while representing significant effort and engineering work, suffered from several fundamental issues that compromised its effectiveness and maintainability:

**Mechanical Design Flaws**: The initial chassis design lacked the structural rigidity required for precise operation. Component mounting points were not optimally positioned, leading to unnecessary stress concentrations and potential failure points. The overall mechanical layout was cluttered and inefficient, making it difficult to achieve the precision we demanded.

**Problematic Sensor Distribution**: The sensor placement strategy in the first robot was suboptimal, with sensors positioned in locations that either compromised their effectiveness or made them vulnerable to damage. The sensor mounting systems were inadequately designed, leading to calibration drift and unreliable readings during operation.

**Maintenance and Accessibility Issues**: Perhaps the most frustrating aspect of the first design was the extreme difficulty in accessing internal components when maintenance or troubleshooting was required. Simple tasks like replacing a sensor or adjusting a mechanical component required extensive disassembly, making the robot impractical for iterative development and field maintenance.

**Electrical System Chaos**: The first robot's electrical system was plagued by an overwhelming tangle of wires that created a maintenance nightmare. The wire management was virtually non-existent, with dozens of connections scattered throughout the chassis without logical organization. This created several critical problems: wires were prone to damage during operation, troubleshooting electrical issues was extremely time-consuming, connections were unreliable due to poor strain relief, and the overall system was prone to electrical interference and signal degradation.

### The Perfected Second Generation

Learning from these challenges, we embarked on a complete redesign that addressed every identified issue while incorporating new innovations and improvements. The result is a robot that represents our vision of engineering excellence realized.

<table>
  <tr>
    <td rowspan="2" align="center" style="border: 3px solid #00bcd4; background: #f0f8ff; padding: 15px;">
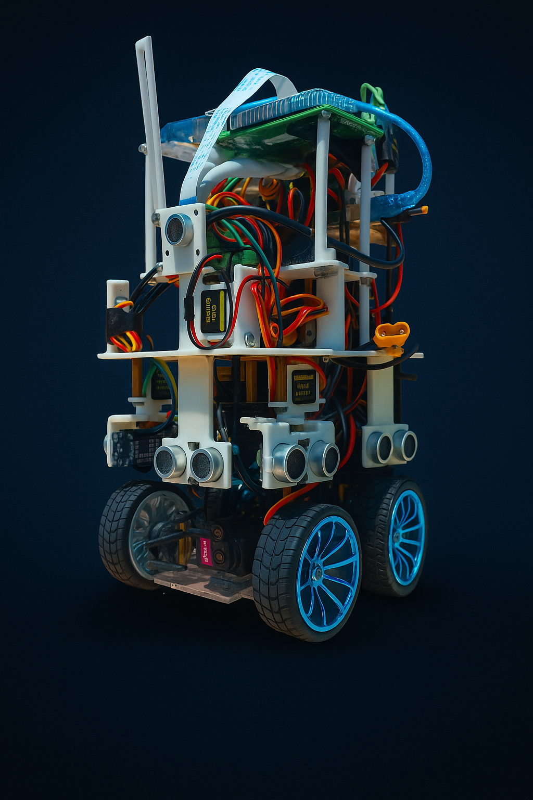
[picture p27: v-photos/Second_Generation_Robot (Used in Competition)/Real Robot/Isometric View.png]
Isometric View
      <br>
      <strong style="color: #00bcd4; font-size: 18px;">🎯 Isometric View</strong>
    </td>
    <td align="center" style="padding: 10px;">
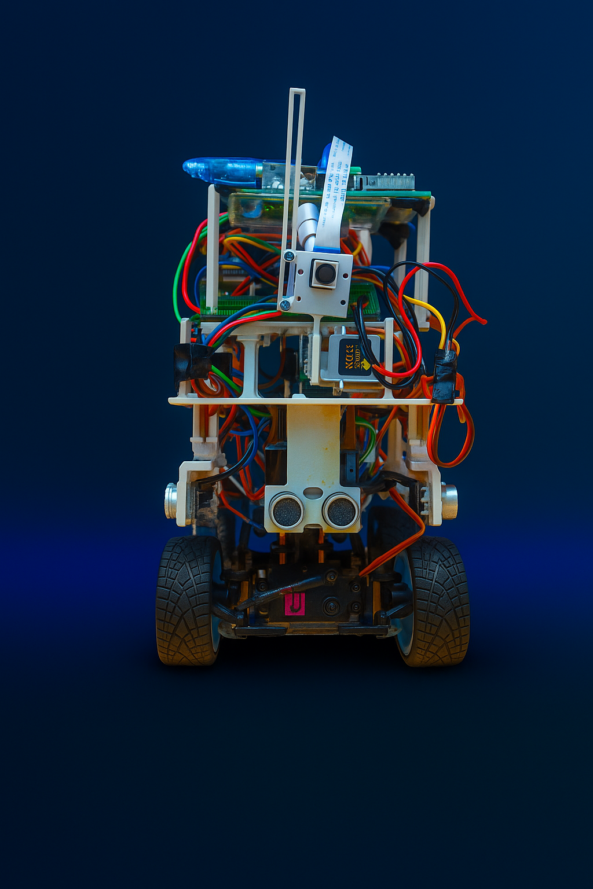
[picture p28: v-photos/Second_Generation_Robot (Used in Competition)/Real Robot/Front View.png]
Front View
      <br>
      <strong>Front View</strong>
    </td>
    <td align="center" style="padding: 10px;">
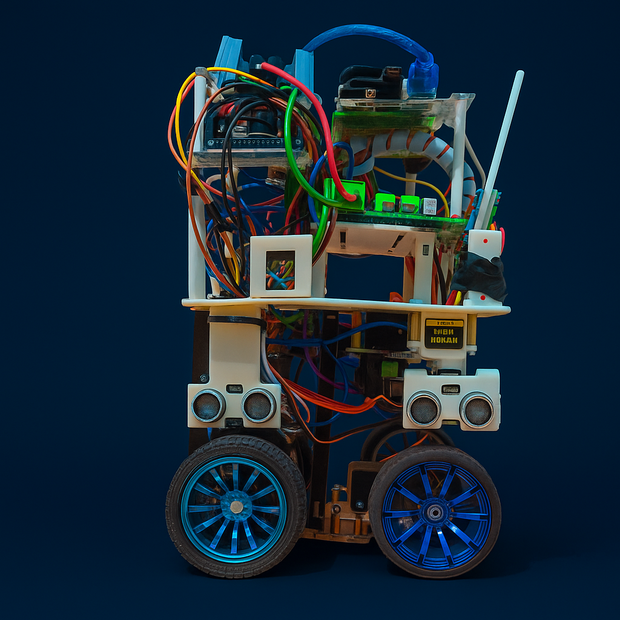
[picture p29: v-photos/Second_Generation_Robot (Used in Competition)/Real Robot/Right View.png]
Right View
      <br>
      <strong>Right View</strong>
    </td>
    <td align="center" style="padding: 10px;">
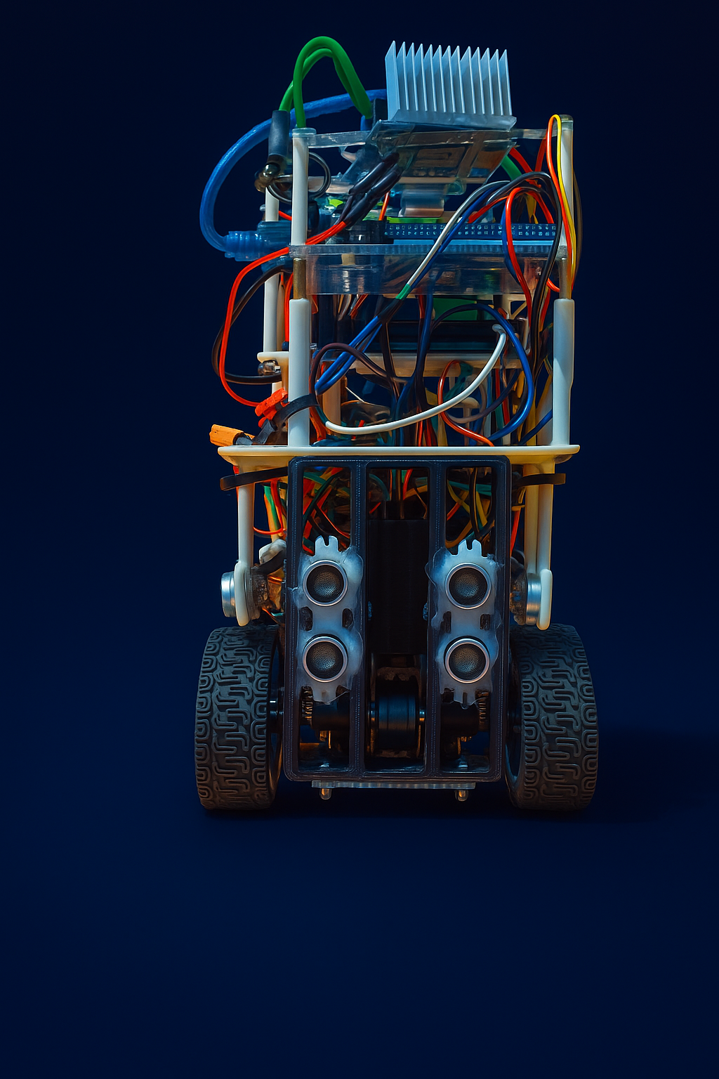
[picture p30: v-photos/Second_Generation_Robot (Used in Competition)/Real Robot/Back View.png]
Back View
      <br>
      <strong>Back View</strong>
    </td>
  </tr>
  <tr>
    <td align="center" style="padding: 10px;">
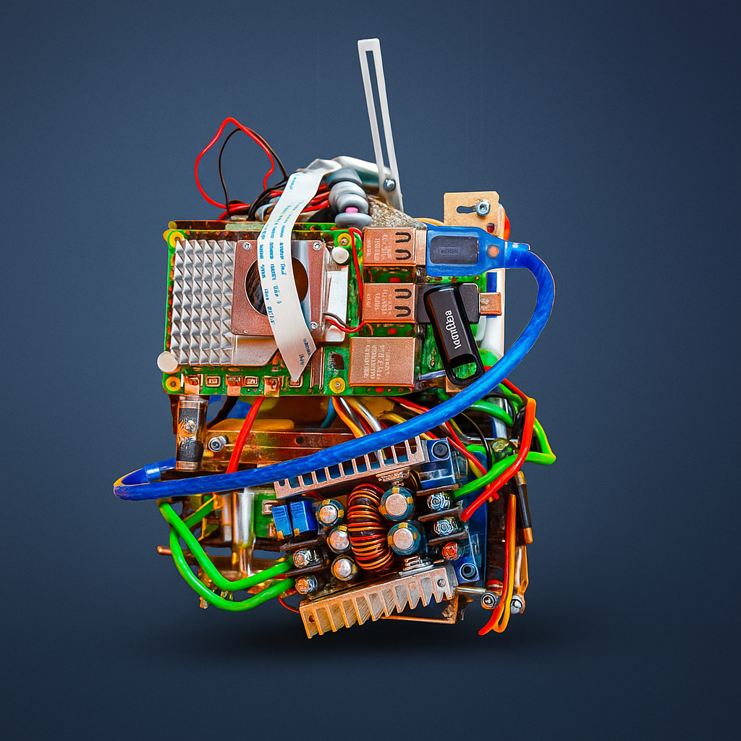
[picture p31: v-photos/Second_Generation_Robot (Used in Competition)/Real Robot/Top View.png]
Top View
      <br>
      <strong>Top View</strong>
    </td>
    <td align="center" style="padding: 10px;">
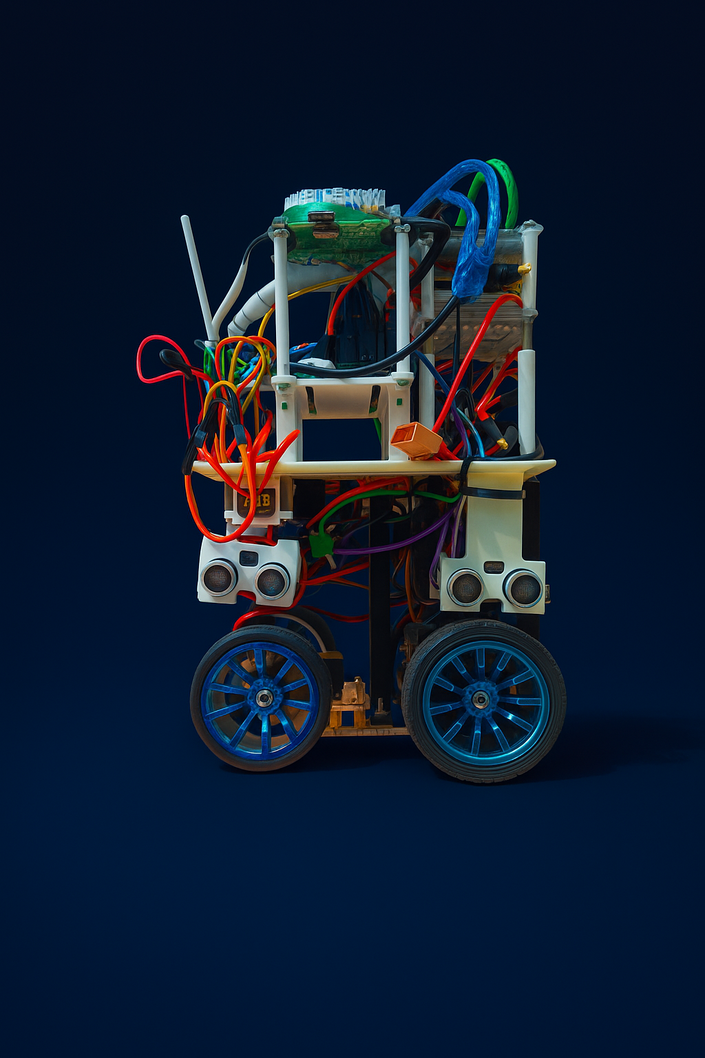
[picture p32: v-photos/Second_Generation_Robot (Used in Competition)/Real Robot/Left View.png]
Left View
      <br>
      <strong>Left View</strong>
    </td>
    <td align="center" style="padding: 10px;">
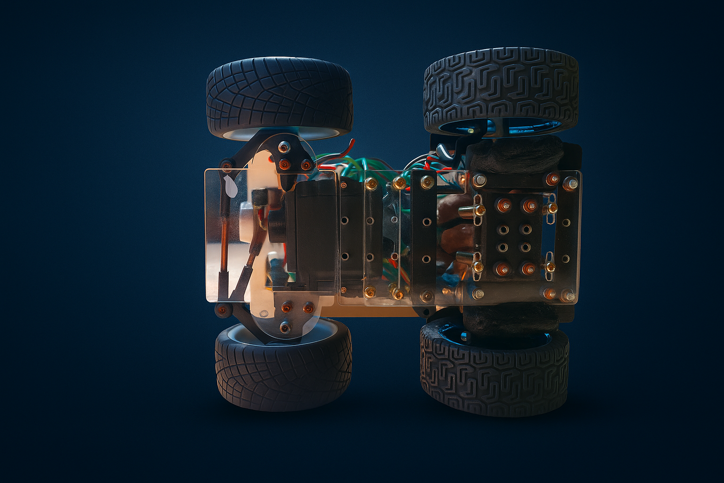
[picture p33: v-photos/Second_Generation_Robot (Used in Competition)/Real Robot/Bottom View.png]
Bottom View
      <br>
      <strong>Bottom View</strong>
    </td>
  </tr>
</table>

The final robot design represents a quantum leap in engineering sophistication and practical functionality. Every aspect has been carefully reconsidered and optimized:

**Superior Structural Integrity**: The new chassis design employs advanced structural engineering principles, with load paths carefully calculated and optimized. The frame geometry provides exceptional rigidity while maintaining minimal weight, achieved through strategic material placement and innovative structural design.

**Optimal Component Accessibility**: Every component in the new design can be accessed without requiring disassembly of other systems. Modular design principles ensure that maintenance tasks can be performed quickly and efficiently, with clear access paths to all critical components.

**Strategic Sensor Integration**: Sensors are now positioned in optimal locations for maximum effectiveness while being protected from environmental hazards. Custom-designed mounting systems ensure stable, repeatable positioning with built-in calibration references.

**Elegant Mechanical Systems**: All mechanical systems have been redesigned with precision manufacturing tolerances and optimal performance characteristics. Gear trains operate smoothly, joints are precisely aligned, and all moving parts are designed for long-term reliability and minimal maintenance.

### Revolutionary Power Management System

One of the most significant innovations in our second-generation design is the development of a custom Power Management System (PMS) that completely eliminates the electrical chaos that plagued our first prototype. Instead of dealing with dozens of individual wire connections scattered throughout the robot, we designed and implemented a centralized power distribution system that functions essentially like a custom PCB circuit board.

This Power Management System represents a paradigm shift in how we approach the robot's electrical architecture. Rather than treating power distribution as an afterthought, we made it a central design consideration from the project's inception. The system provides clean, stable power to all subsystems while maintaining complete electrical isolation between different functional groups.

The PMS offers several critical advantages: it provides regulated power distribution to all components, ensures electrical noise isolation between sensitive systems, offers built-in overcurrent protection for all circuits, enables easy troubleshooting through centralized monitoring points, and maintains professional-grade wire management with proper strain relief and routing.

This sophisticated electrical architecture not only solves the immediate problems of wire management and system reliability but also provides a solid foundation for future expansions and modifications. The modular design of the PMS allows us to easily add new subsystems or modify existing ones without affecting the overall electrical stability of the robot.

*Note: The Power Management System will be discussed in comprehensive detail in the upcoming sections, including circuit diagrams, component specifications, and implementation details.*

## Virtual Robot

### CAD Design and Modeling Philosophy

Our virtual robot development was conducted using advanced 3D CAD modeling software to create a comprehensive digital twin of our physical system. This virtual representation served multiple critical purposes throughout the design process: validating mechanical assemblies before physical manufacturing, identifying potential interference issues between components, optimizing component placement for accessibility and performance, and serving as a master reference for manufacturing specifications.

### Complete System Visualization

<p align="center"> 
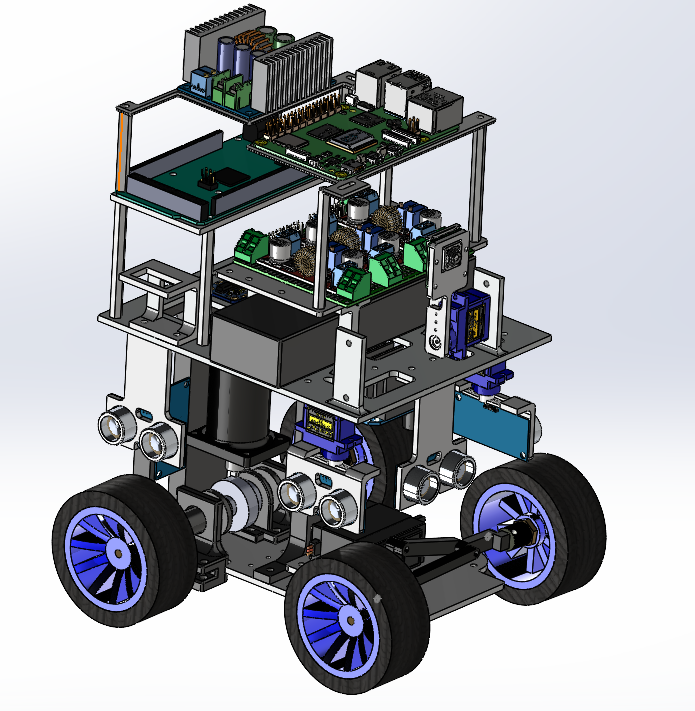
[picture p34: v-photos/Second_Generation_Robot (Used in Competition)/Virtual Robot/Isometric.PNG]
Virtual Robot Isometric View
   
</p>

The virtual robot model showcases our multi-tiered architectural approach, with clearly defined functional zones distributed across multiple levels. This layered design philosophy maximizes component density while maintaining excellent accessibility for maintenance and troubleshooting operations.

### Multi-Tiered Architecture Design

**Upper Level - Control Systems**: The top tier houses the primary computing and control electronics, including the main processing unit with integrated cooling systems, power management circuitry with status indicators, and primary sensor interface boards strategically positioned for optimal signal routing.

**Middle Level - Sensor Integration**: The intermediate level features our comprehensive sensor array with custom mounting solutions designed for optimal positioning, environmental protection housings that maintain sensor accuracy while providing physical protection, and modular connection systems that enable rapid sensor replacement or reconfiguration.

**Lower Level - Mechanical Systems**: The bottom tier contains our precision-engineered drivetrain, including the custom differential gear mechanism, Ackermann steering system with servo control, wheel assemblies with high-performance tires, and structural mounting points that distribute operational loads effectively.

### Engineering Validation Through Virtual Modeling

The virtual robot served as a critical validation tool throughout our design process. We conducted comprehensive interference checks to ensure all components had adequate clearance during operation, performed stress analysis simulations on critical structural elements, validated cable routing paths and strain relief requirements, and confirmed maintenance access points for all serviceable components.

### Manufacturing Integration

Our CAD model was directly integrated with our manufacturing workflow, providing precise specifications for 3D printing parameters and material requirements, exact dimensions and tolerances for laser-cut components, assembly sequences and torque specifications for mechanical connections, and complete bill of materials with sourcing information for all purchased components.

The virtual robot model represents not just a visualization tool, but a comprehensive engineering database that guided every aspect of our physical implementation, ensuring that our final robot matched our design intent with exceptional precision and reliability.

## Robot's Design Lessons

Through our intensive two-month design journey and complete prototype iteration, we gained invaluable insights that fundamentally shaped our engineering approach. These lessons learned represent critical knowledge that will guide future robotics projects and serve as a foundation for continuous improvement.

### Lesson 1: Precision Manufacturing Tolerances Are Non-Negotiable

Our experience with the differential gear mechanism taught us that in precision robotics, there is no room for "close enough" tolerances. The 1-millimeter clearance issue that forced a complete redesign demonstrated that every measurement must be calculated with meticulous accuracy and validated through rigorous testing. We learned to always build in appropriate safety margins while maintaining the precision required for optimal performance.

### Lesson 2: Accessibility Must Be Designed In, Not Added Later

The maintenance nightmare of our first prototype taught us that component accessibility cannot be an afterthought. Every component must be reachable for maintenance, calibration, and replacement without requiring extensive disassembly. This lesson fundamentally changed how we approach mechanical layout – we now design maintenance access paths before finalizing component placement.

### Lesson 3: Electrical Architecture Defines System Reliability

The chaotic wiring of our first robot revealed that electrical system design is just as critical as mechanical engineering. Poor wire management doesn't just create aesthetic problems – it introduces reliability issues, electromagnetic interference, and maintenance complications. We learned that investing in proper power distribution and signal routing from the beginning saves countless hours of troubleshooting later.

### Lesson 4: Sensor Placement Strategy Determines Performance

Strategic sensor positioning emerged as a crucial design consideration that affects both performance and maintainability. We learned that sensors must be positioned not only for optimal functionality but also with consideration for protection from environmental factors, ease of calibration, and accessibility for replacement or adjustment.

### Lesson 5: Modular Design Enables Rapid Iteration

Our redesign experience highlighted the importance of modular architecture. Systems designed as discrete, interchangeable modules allow for rapid prototyping, easier troubleshooting, and the ability to upgrade individual subsystems without affecting the entire platform. This approach accelerated our development timeline and improved system reliability.

### Lesson 6: Manufacturing Method Selection Impacts Design Feasibility

We discovered that choosing the right manufacturing method for each component is crucial for both performance and cost-effectiveness. The combination of 3D printing for complex geometries and laser cutting for precision flat components allowed us to optimize each part for its specific function while maintaining manufacturing efficiency.

### Lesson 7: Early Prototype Testing Prevents Expensive Mistakes

Despite the significant effort invested in our first prototype, the lessons learned from its limitations were invaluable. We learned that early, honest evaluation of prototype performance is essential – it's better to identify and address fundamental design flaws early than to incrementally improve a fundamentally flawed design.

### Lesson 8: Documentation and Design Rationale Are Essential

Throughout the redesign process, we learned the critical importance of documenting design decisions and the rationale behind them. This documentation proved invaluable when troubleshooting issues and making informed decisions about design modifications. Future projects will benefit from comprehensive design documentation from the project's inception.

### Lesson 9: Performance Requirements Must Drive Design Decisions

We learned that every design decision must be traceable back to specific performance requirements. Features that seem convenient or aesthetically pleasing must be evaluated against their impact on the system's primary objectives. This disciplined approach ensures that engineering effort is focused on elements that directly contribute to mission success.

### Lesson 10: Perfection Requires Patience and Persistence

Perhaps our most important lesson was that achieving true engineering excellence requires patience, persistence, and the willingness to start over when necessary. Our two-month development timeline and complete redesign process taught us that rushing to meet arbitrary deadlines compromises the final product's quality. True engineering excellence cannot be hurried – it must be carefully cultivated through methodical attention to detail and unwavering commitment to quality.

---
# Mobility Management

## Motor Selection and Implementation

### Selected Motors: Specifications and Rationale

Our mobility system employs two distinct motor types, each selected for specific performance requirements and operational characteristics within our autonomous vehicle platform.

#### Primary Drive Motor: JGA25-370 245 RPM DC Motor

<p align="center"> 
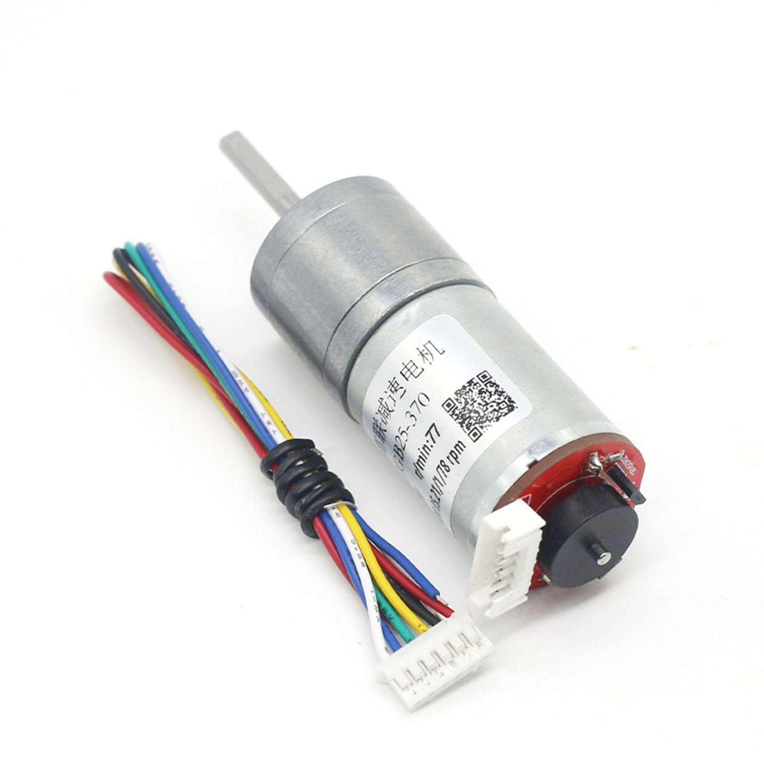
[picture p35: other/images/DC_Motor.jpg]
JGA25-370 DC Motor
  
</p>

The primary drivetrain utilizes a JGA25-370 DC motor operating at 245 RPM, selected through comprehensive analysis of torque requirements, power efficiency, and cost-effectiveness criteria. The motor specifications demonstrate optimal performance characteristics for our application:

At 12V operation, the motor delivers 350 RPM no-load speed with 0.1A current draw, achieving maximum efficiency at 245 RPM with 1.4 kg⋅cm torque output and 2.4W power consumption. The motor's blockage specifications indicate 5.2 kg⋅cm stall torque with 2.2A current draw, providing substantial reserve capacity for overcoming static friction and handling unexpected load conditions.

The selection criteria prioritized three critical factors: cost-effectiveness for budget-conscious development, adequate power output to propel our 1,475g robot mass, and high efficiency to maximize battery life during extended autonomous operation. The integrated gearbox provides a 3:1 gear reduction ratio, effectively tripling the output torque to 4.2 kg⋅cm while reducing output speed to approximately 82 RPM, creating an optimal balance between torque delivery and vehicle velocity.

#### Steering Actuator: MG996R Servo Motor

<p align="center"> 
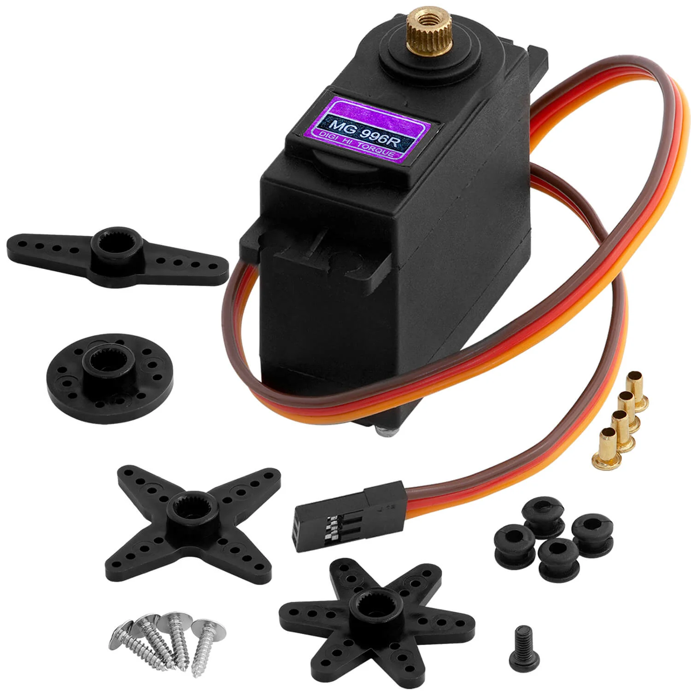
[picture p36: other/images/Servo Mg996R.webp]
MG996R Servo Motor
  
</p>

The steering system employs an MG996R high-torque servo motor, specifically selected for its exceptional torque output and precision control capabilities. The servo specifications include 9.4 kg⋅cm stall torque at 4.8V and 11 kg⋅cm at 6V, with operating speeds of 0.17 s/60° and 0.14 s/60° respectively.

This servo selection addresses the substantial torque requirements of our Ackermann steering mechanism while providing the precision control necessary for accurate trajectory following. The servo's robust double ball bearing design ensures long-term reliability under continuous operation, while its 55g weight contributes minimally to overall vehicle mass.

### Motor Control Implementation

#### Drive Motor Control System

<p align="center"> 
 BTS7960 Motor Driver 
</p>

The DC drive motor utilizes Pulse Width Modulation (PWM) control through a BTS7960 motor driver, providing bidirectional speed control with high current handling capability. The BTS7960 driver offers several critical advantages: 43A peak current handling capacity far exceeding our motor's 2.2A maximum draw, built-in overcurrent and thermal protection, and smooth PWM control enabling precise speed regulation.

#### Steering Control Architecture

<p align="center"> 
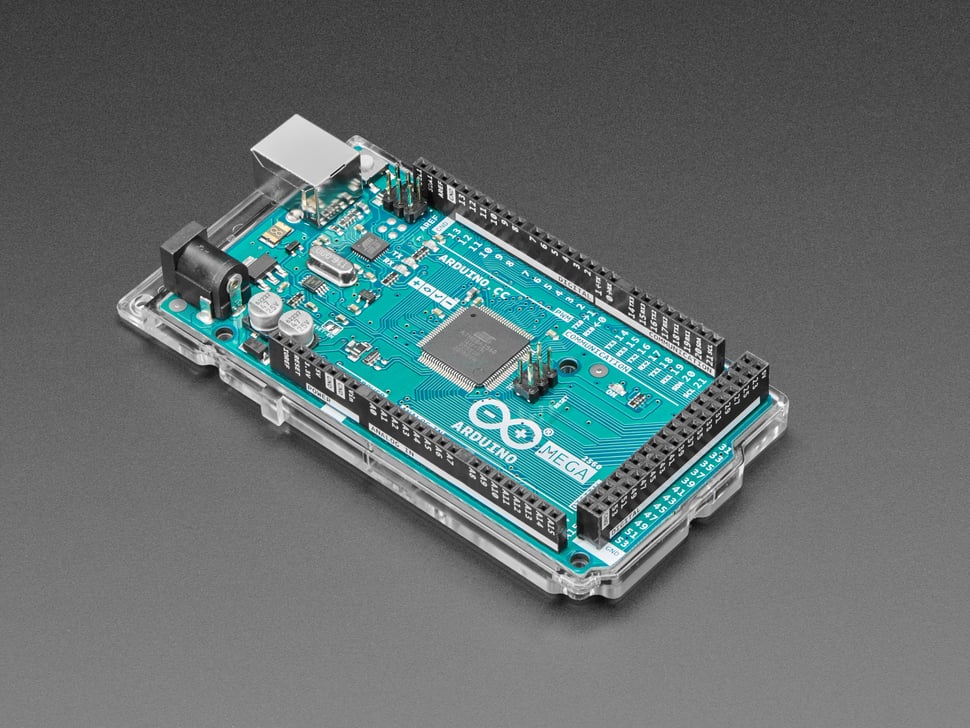
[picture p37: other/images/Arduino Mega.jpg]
Arduino Mega Microcontroller
  
</p>

The MG996R servo receives direct PWM signals from our Arduino Mega microcontroller, enabling immediate response to steering commands without additional driver circuitry. This direct control approach minimizes latency in the steering response loop, critical for maintaining trajectory accuracy during high-speed autonomous navigation.

## Chassis Design and Structural Implementation

### Material Selection and Structural Philosophy

Our chassis architecture employs a hybrid material approach, combining 3mm plexiglass panels for primary structural elements with PLA 3D-printed components for complex mechanical interfaces. This material selection optimizes the balance between structural rigidity, manufacturing precision, and overall system weight.

The plexiglass panels provide excellent dimensional stability and high strength-to-weight ratio, while the 3D-printed components enable complex geometries impossible with traditional manufacturing methods. The overall vehicle dimensions measure 29cm length × 17.5cm width × 29cm height, with a total system weight of 1,475g.

### Multi-Level Chassis Configuration

#### Ground Level: Drivetrain Integration

<p align="center"> 
 Back Plexi with Differential Mechanism 
</p>

The rear section houses our custom differential mechanism integrated with the JGA25-370 DC motor. The back plexi panel is positioned slightly lower than the front section, strategically shifting the center of mass forward to improve vehicle stability during acceleration and cornering maneuvers.

<p align="center"> 
 Front Plexi with Ackermann Steering 
</p>

The front section accommodates the Ackermann steering mechanism with the MG996R servo motor. This configuration ensures optimal weight distribution while maintaining accessibility for maintenance and calibration procedures.

## Component Integration and Mounting Strategy

### Primary Control Systems

<p align="center"> 
 Raspberry Pi 5 with Active Cooling 
</p>

The upper chassis level houses the Raspberry Pi 5 (8GB RAM) with active cooling system, serving as the primary computational platform for autonomous navigation algorithms. The active cooler ensures consistent performance under continuous operation while maintaining optimal processing speeds.

<p align="center"> 
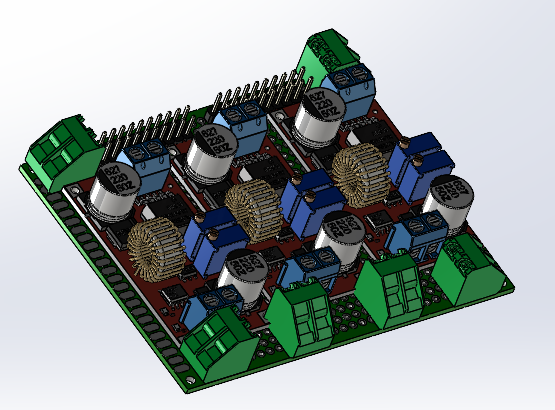
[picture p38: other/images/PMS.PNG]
Power Management System
  
</p>

Our custom Power Management System (PMS) provides regulated power distribution to all subsystems while maintaining electrical isolation between sensitive circuits. This centralized approach eliminates the wire management issues encountered in our first prototype while providing overcurrent protection for all circuits.

### Sensor Array Integration

<p align="center">
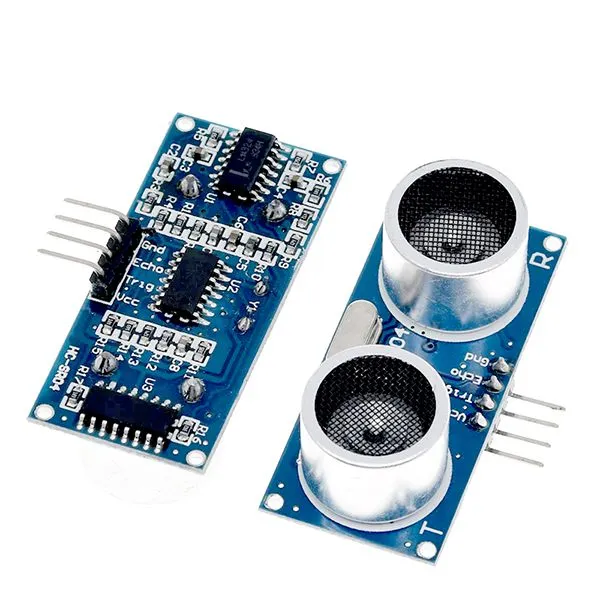
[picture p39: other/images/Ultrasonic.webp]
Seven Ultrasonic Sensor Array
  
</p>

Seven ultrasonic sensors are strategically positioned to provide comprehensive environmental awareness. The sensors are mounted below the 9cm height threshold to ensure reliable wall detection capabilities throughout the competition environment.

<p align="center">
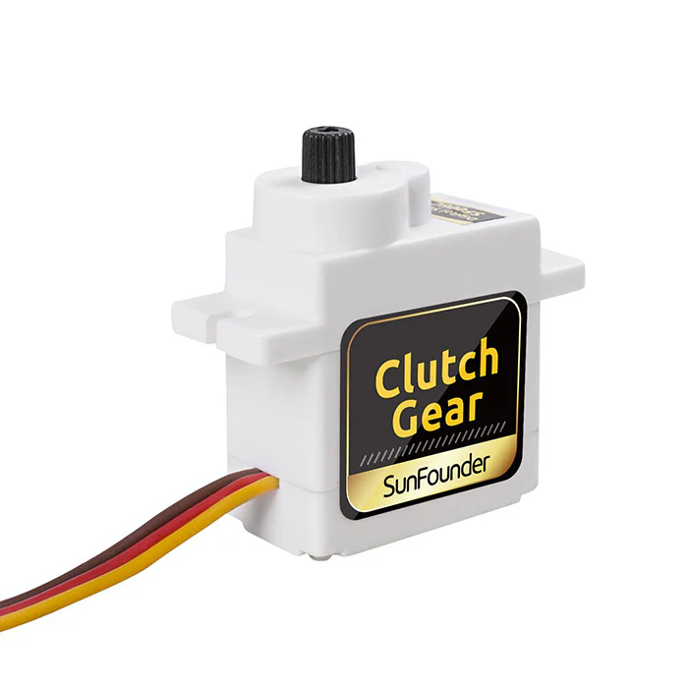
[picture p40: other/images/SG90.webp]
SG90 Tower Pro Servos
  
</p>

Three SG90 Tower Pro servos enable dynamic ultrasonic sensor positioning, maintaining perpendicular orientation to walls regardless of vehicle attitude. This active positioning system significantly improves sensor accuracy and reliability.

<p align="center">
  MPU6050 IMU Sensor
</p>

The MPU6050 inertial measurement unit provides precise orientation and acceleration data, enabling accurate dead reckoning and complementing the ultrasonic sensor array for robust navigation.

<p align="center">
  Arducam 64 MP Hawk-Eye Camera
</p>

The Arducam 64 MP Hawk-Eye camera module provides high-resolution visual sensing capabilities for advanced computer vision tasks. Its 64-megapixel sensor enables detailed environmental mapping, precise object recognition, and enhanced autonomous navigation through visual SLAM algorithms. The camera's wide field of view and exceptional image quality support real-time obstacle detection and path planning optimization.

<p align="center">
  IR Sensor Positioning
</p>

The infrared sensor is positioned at maximum distance from the main chassis body, optimizing its effectiveness for parking maneuvers and obstacle detection scenarios. This extended positioning minimizes interference from chassis reflections while maximizing detection range.
### Power Source

<p align="center"> 
 Li-Poly Battery 11.1V 2200mAh 
</p>

The system is powered by an 11.1V, 2200mAh Li-Poly battery, providing sufficient capacity for extended autonomous operation while maintaining compact form factor. The battery placement contributes to the forward center of mass shift, enhancing vehicle stability characteristics.

## Engineering Principles and Performance Analysis

### Torque and Power Calculations

The drivetrain's mechanical advantage is achieved through the integrated 3:1 gear reduction, transforming the motor's base specifications into optimal output characteristics for vehicle propulsion.

**Motor Torque Analysis:**
- Base motor torque at 12V: 1.4 kg⋅cm (maximum efficiency point)
- Gear reduction ratio: 3:1
- Output torque: 
 $$T_{output} = T_{motor} \times GR = 1.4 \times 3 = 4.2 \text{ kg⋅cm}$$
- Wheel radius: 32mm (rear wheels)
- Tractive force: 
 $$F_{tractive} = \frac{T_{output}}{r_{wheel}} = \frac{4.2 \text{ kg⋅cm}}{3.2 \text{ cm}} = 1.31 \text{ kg} \approx 12.85 \text{ N}$$

**Speed Calculations:**
- Motor speed at maximum efficiency: 245 RPM
- Output shaft speed: 
 $$\omega_{output} = \frac{\omega_{motor}}{GR} = \frac{245}{3} = 81.67 \text{ RPM}$$
- Linear velocity: 
 $$v_{linear} = \frac{\omega_{output} \times 2\pi \times r_{wheel}}{60} = \frac{81.67 \times 2\pi \times 3.2}{60} = 27.35 \text{ cm/s} \approx 0.27 \text{ m/s}$$

**Power Requirements:**
- Vehicle weight: 1,475g = 14.46 N
- Rolling resistance coefficient (estimated): 0.02
- Rolling resistance force: 
 $$F_{rolling} = \mu_{rolling} \times W = 0.02 \times 14.46 = 0.29 \text{ N}$$
- Power required for constant velocity: 
 $$P_{required} = F_{rolling} \times v_{linear} = 0.29 \times 0.27 = 0.078 \text{ W}$$
- Motor efficiency at operating point: ~90%
- Actual power consumption: 
 $$P_{actual} = \frac{P_{required}}{\eta} = \frac{0.078}{0.90} = 0.087 \text{ W}$$

These calculations demonstrate substantial power reserves, ensuring reliable performance under varying load conditions and providing acceleration capability for dynamic maneuvering.

### Center of Mass Optimization

The chassis configuration strategically positions the center of mass forward of the geometric center through differential plexi height positioning. This forward bias provides several dynamic advantages: improved traction on drive wheels during acceleration, enhanced stability during cornering maneuvers, and reduced tendency for rear wheel lift during aggressive acceleration.

The center of mass calculations were performed using SolidWorks mass properties analysis of our complete virtual robot model, enabling precise component placement optimization before physical assembly.

### Mechanical Design Principles

The drivetrain implementation incorporates several fundamental mechanical engineering principles:

**Mechanical Advantage:** The 3:1 gear reduction multiplies available torque while reducing speed, optimizing the motor's power curve for vehicle propulsion requirements.

**Load Distribution:** The differential mechanism ensures equal torque distribution to both drive wheels while allowing speed differentiation during turning maneuvers.

**Kinematic Optimization:** The Ackermann steering geometry ensures all wheels follow proper turning radii, minimizing tire scrubbing and maximizing steering efficiency.

**Structural Integrity:** The chassis design employs triangulated load paths and strategic reinforcement to handle operational loads while minimizing weight penalty.

---

# Power and Sense Management

## Battery Specifications and Power Analysis

### Primary Power Source: Zeee Li-Poly Battery

Our robot utilizes a high-performance Zeee Li-Poly battery with the following specifications:
- **Voltage:** 11.1V (3S configuration)
- **Capacity:** 2200mAh
- **Discharge Rate:** 50C continuous
- **Maximum Current Output:** 110A continuous
- **Weight:** Approximately 185g
- **Connector Type:** XT60

### Power Consumption Analysis and Runtime Calculations

Based on our comprehensive component analysis, the following power consumption calculations determine our operational runtime under various scenarios.

#### Component Power Consumption Summary

**Typical Operating Scenario:**
- Raspberry Pi 5 with active cooler: 15W
- Arduino Mega 2560: 2W  
- JGA25-370 DC Motor: 2.4W (at efficiency point)
- MG996R Servo (steering): 3W (average operation)
- 3× SG90 Servos: 1.5W (0.5W each)
- 7× HC-SR04 Ultrasonic sensors: 1.05W (0.15W each)
- MPU6050 IMU: 0.5W
- IR Sensor: 0.3W
- BTS7960 Motor Driver: 1W
- Power Management System losses: 2W

**Total Typical Power Consumption:**
$$P_{typical} = 15 + 2 + 2.4 + 3 + 1.5 + 1.05 + 0.5 + 0.3 + 1 + 2 = 28.75W$$

**Worst-Case Operating Scenario:**
- Raspberry Pi 5 under full load with cooler: 20W
- Arduino Mega 2560: 3W
- DC Motor at maximum efficiency: 2.4W
- MG996R Servo under load: 6W
- 3× SG90 Servos active positioning: 3W (1W each)
- 7× HC-SR04 Ultrasonic sensors: 1.4W (0.2W each)
- MPU6050 IMU: 0.5W
- IR Sensor: 0.3W
- BTS7960 Motor Driver: 2W
- Power Management System losses: 3W

**Total Worst-Case Power Consumption:**
$$P_{worst} = 20 + 3 + 2.4 + 6 + 3 + 1.4 + 0.5 + 0.3 + 2 + 3 = 41.6W$$

#### Battery Runtime Calculations

**Available Energy:**
$$E_{available} = V_{battery} \times Capacity = 11.1V \times 2.2Ah = 24.42Wh$$

**Typical Operating Runtime:**
$$t_{typical} = \frac{E_{available}}{P_{typical}} = \frac{24.42Wh}{28.75W} = 0.85 \text{ hours} = 51 \text{ minutes}$$

**Worst-Case Operating Runtime:**
$$t_{worst} = \frac{E_{available}}{P_{worst}} = \frac{24.42Wh}{41.6W} = 0.587 \text{ hours} = 35 \text{ minutes}$$

**Safety Factor Runtime (80% battery usage):**
$$t_{safe} = t_{typical} \times 0.8 = 51 \times 0.8 = 40.8 \text{ minutes}$$

These calculations demonstrate that our battery provides sufficient capacity for multiple competition runs, with typical runtime exceeding 50 minutes and safe operational time of approximately 41 minutes.

## Power Management System (PMS)

### Custom Power Distribution Architecture

<p align="center"> 
 Power Management System Schematic 
</p>

### Star Topology Power Distribution

<p align="center"> 
 Star Technique Power Distribution 
</p>

The star topology power distribution technique employed in our PMS offers significant advantages over conventional daisy-chain power routing. This configuration ensures that each component receives clean, stable power directly from the central distribution point, eliminating voltage drops and current-induced interference between subsystems.

**Key Advantages of Star Distribution:**
- **Current Isolation:** Each component's current draw does not affect other components' supply voltage
- **Reduced Voltage Drop:** Minimizes resistive losses in power distribution cables
- **Simplified Troubleshooting:** Centralized connection point enables rapid fault isolation
- **Enhanced Reliability:** Single-point failure mode confined to individual branches
- **Professional Cable Management:** Clean, organized wiring reduces maintenance complexity

The 50C continuous discharge rate of our Li-Poly battery (110A maximum) provides substantial current capacity, ensuring that simultaneous high-current demands from multiple subsystems can be met without voltage sag or performance degradation.

**Comparison with First Generation:**
The transformation from our chaotic first-generation wiring to the organized second-generation PMS demonstrates the critical importance of proper electrical architecture in robotics applications. The star topology eliminated the "wire spaghetti" syndrome while improving system reliability and maintainability.

<table align="center">
  <tr>
    <td style="vertical-align: middle; text-align: center;">
      First Generation Robot
    </td>
    <td style="vertical-align: middle; text-align: center;">
      Second Generation Robot
    </td>
  </tr>
</table>

## Sensor Integration and Selection Rationale

### Ultrasonic Sensor Array: HC-SR04

Our robot employs seven HC-SR04 ultrasonic sensors strategically positioned to provide comprehensive environmental awareness. The specific positioning strategy and operational algorithms will be detailed in the challenge-solving sections, as their implementation is closely tied to navigation strategies.

**Power Consumption per HC-SR04:**
$$P_{ultrasonic} = V \times I = 5V \times 0.03A = 0.15W \text{ (typical)}$$

**Total Array Consumption:**
$$P_{array} = 7 \times 0.15W = 1.05W$$

The perpendicular distance measurement capability is critical for accurate wall-following algorithms. When sensors maintain perpendicular orientation to surfaces, measurement accuracy improves significantly compared to angled readings that require trigonometric correction.

### Dynamic Sensor Positioning: SG90 Servo Motors

Three SG90 Tower Pro servo motors enable dynamic positioning of critical ultrasonic sensors, maintaining optimal measurement angles regardless of robot orientation. This active positioning system significantly improves navigation accuracy in complex environments.

**SG90 Power Consumption:**
$$P_{SG90} = V \times I = 5V \times 0.1A = 0.5W \text{ (per servo, typical operation)}$$

### Inertial Measurement: MPU6050 IMU

The MPU6050 inertial measurement unit serves as our primary orientation reference, providing critical yaw axis data for navigation algorithms. While we initially specified the BNO055 sensor for its superior sensor fusion capabilities, supply chain constraints necessitated the MPU6050 selection.

The MPU6050 proves highly effective for our application, as we primarily require yaw (Z-axis rotation) data for heading maintenance and turn angle measurement. The sensor's 16-bit ADC resolution and integrated digital motion processor provide sufficient accuracy for autonomous navigation requirements.

**MPU6050 Power Consumption:**
$$P_{MPU6050} = V \times I = 3.3V \times 0.15A = 0.5W$$

### Infrared Detection: IR Sensor

The infrared sensor is strategically positioned at maximum distance from the main chassis body to optimize detection range and minimize interference from chassis reflections. This sensor plays a specialized role in parking maneuvers, with detailed implementation to be covered in the parking algorithm section.

**IR Sensor Power Consumption:**
$$P_{IR} = V \times I = 5V \times 0.06A = 0.3W$$

## Primary Processing Systems

### Arduino Mega 2560: Sensor Interface and Control

The Arduino Mega 2560 serves as our primary sensor interface and real-time control processor. This microcontroller selection was driven by practical considerations: cost-effectiveness as one of the most economical microcontroller platforms available, extensive I/O capability with 54 digital pins and 16 analog inputs to accommodate our comprehensive sensor array, and proven reliability in robotics applications.

The Arduino Mega handles all sensor data acquisition, motor control, and real-time navigation decisions except computer vision processing. This division of computational tasks optimizes system performance while maintaining cost-effectiveness.

**Arduino Mega Power Consumption:**
$$P_{Arduino} = V \times I = 8V \times 0.25A = 2W \text{ (typical operation)}$$

### Raspberry Pi 5: Computer Vision Processing
The Raspberry Pi 5 with 8GB RAM configuration provides the computational power required for real-time computer vision processing. The substantial RAM capacity enables efficient image processing algorithms while maintaining responsive system performance.

**Active Cooling Necessity:**
The active cooling system is essential for maintaining optimal performance under challenging environmental conditions. High ambient temperatures, particularly during summer competition periods, can cause thermal throttling that significantly degrades processing performance. The active cooler ensures consistent operation at full computational capacity.

**Raspberry Pi 5 Power Consumption with Cooler:**
$$P_{Pi5} = V \times I = 12V \times 1.25A = 15W \text{ (typical with cooling)}$$

### Inter-Processor Communication

Communication between the Arduino Mega and Raspberry Pi 5 is established through USB serial connection, providing reliable data exchange for computer vision results and navigation commands. This communication architecture enables efficient task distribution while maintaining real-time responsiveness.

## Complete System Wiring Architecture

<p align="center"> 
 Complete Robot Wiring Schematic 
</p>

The comprehensive wiring schematic illustrates the integration of all electrical subsystems through our custom Power Management System. This professional-grade documentation enables accurate system replication and facilitates troubleshooting procedures.

## Bill of Materials (BOM)

| Component Category | Item Description | Quantity | Unit Cost (USD) | Total Cost (USD) |
|---|---|---|---|---|
| **Mechanical Structure** | Custom Design (Plexiglass & 3D Printed Parts) | 1 | $150.00 | $150.00 |
| **Drive System** | JGA25-370 245 RPM DC Motor | 2 | $25.00 | $50.00 |
| **Steering System** | MG996R High-Torque Servo Motor | 3 | $7.00 | $21.00 |
| **Drivetrain** | Differential Gear Assembly | 2 | $15.00 | $30.00 |
| **Steering Mechanism** | Ackermann Steering Kit | 1 | $20.00 | $20.00 |
| **Wheels** | Rear Wheel Assembly (64mm) | 2 | $5.00 | $10.00 |
| **Wheels** | Front Wheel Assembly (56mm) | 2 | $3.00 | $6.00 |
| **Hardware** | Hexagonal Rods, Connectors, Screws Kit | 1 | $12.00 | $12.00 |
| **Distance Sensors** | HC-SR04 Ultrasonic Sensor | 10 | $1.00 | $10.00 |
| **Servo Actuators** | SG90 Tower Pro Micro Servo | 3 | $2.50 | $7.50 |
| **IMU Sensor** | MPU6050 6-DOF Inertial Measurement Unit | 2 | $7.00 | $14.00 |
| **Power Management** | PMS Components (Junctions, Board, Buck Converters) | 1 | $8.00 | $8.00 |
| **Power Conversion** | 300W 20A DC-DC Buck Converter Module | 1 | $7.00 | $7.00 |
| **Microcontroller** | Arduino Mega 2560 R3 | 1 | $55.00 | $55.00 |
| **Main Processor** | Raspberry Pi 5 (8GB RAM) | 1 | $110.00 | $110.00 |
| **Cooling System** | Active Cooler for Raspberry Pi 5 | 1 | $12.00 | $12.00 |
| **Vision System** | ArduCam 64MP Hawk-eye Camera Module | 1 | $100.00 | $100.00 |
| **Power Source** | Li-Poly Battery 11.1V 2200mAh (50C) | 2 | $40.00 | $80.00 |
| **Charging System** | SkyRC iMAX B6 Mini Balance Charger | 1 | $45.00 | $45.00 |
| **Motor Control** | BTS7960 High-Current Motor Driver | 1 | $15.00 | $15.00 |
| **Detection Sensor** | IR Sensor Module | 1 | $3.00 | $3.00 |
| | | | **Total System Cost** | **$766.50** |

**Note:** Quantities reflect total purchased including backup units for damaged components during development and testing phases.

This comprehensive power and sense management system provides robust, reliable operation while maintaining professional-grade electrical architecture suitable for competitive robotics applications.

---
# Obstacle Management

## Autonomous Robot Navigation Algorithm for Open Challenge

### Algorithm Flow

1. **Initialization**: Acquire sensor readings and assess initial positioning
2. **Wall Avoidance**: Apply P-control for maintaining safe wall clearance
3. **Reference Tracking**: Employ PD-control for heading maintenance
4. **Opening Detection**: Monitor for navigation opportunities
5. **Adaptive Turning**: Execute calibrated turning maneuvers
6. **Reference Update**: Adjust heading reference post-turn
7. **Iteration**: Repeat until mission completion

### Algorithm Structure

#### 1. Initial Position Assessment

<p align="center"> 
 Open Challenge Algorithm 
</p>

The system initiates by acquiring distance measurements from bilateral ultrasonic sensors to establish the robot's spatial relationship with surrounding walls:

```
d_left = ultrasonic_left.read()
d_right = ultrasonic_right.read()
```

Where `d_left` and `d_right` represent the measured distances to the left and right walls, respectively.

#### 2. Wall Avoidance Control

The algorithm implements a proportional (P) controller for wall avoidance when proximity thresholds are exceeded:

##### Right Wall Avoidance

<p align="center"> 
 Open Challenge Algorithm 
</p>

When `d_right < threshold_min`:

```
u_avoid = Kp_wall × (d_setpoint - d_right)
```

<p align="center"> 
 Open Challenge Algorithm 
</p>

##### Left Wall Avoidance

When `d_left < threshold_min`:

```
u_avoid = -Kp_wall × (d_setpoint - d_left)
```

Where:
- `Kp_wall` is the proportional gain for wall avoidance
- `d_setpoint = 20 cm` (minimum desired wall clearance)
- `threshold_min = 20 cm`

#### 3. Reference Tracking Control

<p align="center"> 
 Open Challenge Algorithm 
</p>

When adequate clearance from both walls is maintained, the system employs a proportional-derivative (PD) controller to track the magnetometer (MPU) heading reference:

```
e_heading = θ_reference - θ_current
u_track = Kp_heading × e_heading + Kd_heading × (de_heading/dt)
```

Where:
- `θ_reference` is the desired heading angle
- `θ_current` is the current heading from the MPU
- `Kp_heading` and `Kd_heading` are the proportional and derivative gains, respectively

#### 4. Adaptive Turning Logic

The algorithm executes turning maneuvers when either ultrasonic sensor detects an opening (distance > 120 cm):

##### Turn Initiation Condition

<p align="center"> 
 Open Challenge Algorithm 
</p>

```
if (d_left > 120 cm) OR (d_right > 120 cm):
    initiate_turn()
```

##### Turn Execution

<p align="center"> 
 Open Challenge Algorithm 
</p>

The robot continues turning until reaching the calibrated angular offset:

```
θ_target = θ_reference ± 70°
```

Where the sign depends on the turning direction:
- Counter-clockwise (CCW): `θ_target = θ_reference + 70°`
- Clockwise (CW): `θ_target = θ_reference - 70°`

##### Reference Update
Upon turn completion, the heading reference is updated:

```
θ_reference_new = θ_reference_old ± 90°
```

Where:
- CCW turn: `θ_reference_new = θ_reference_old + 90°`
- CW turn: `θ_reference_new = θ_reference_old - 90°`

#### 5. Mission Completion Criteria

The algorithm continues execution until three complete navigation laps are achieved:

```
while (lap_count < 3):
    execute_navigation_cycle()
    lap_count += detect_lap_completion()
```

**The Following is a gif file that explains the Open Challenge algorithm:**
<p align="center"> 
 Open Challenge Algorithm 
</p>

### Control Parameters

| Parameter | Value | Description |
|---|---|---|
| `d_setpoint` | 20 cm | Minimum wall clearance distance |
| `threshold_min` | 20 cm | Wall proximity threshold |
| `threshold_max` | 120 cm | Opening detection threshold |
| `turn_offset` | 70° | Calibrated turning angle offset |
| `reference_increment` | 90° | Heading reference update step |
| `target_laps` | 3 | Required number of navigation laps |

#### 6. Flowchart of the Algorithm

**Note:You can click on the images so they become clearer**

<p align="center"> 
  <a href="other/images/Open-Challenge/Algorithm Flowchart Part1.PNG" target="_blank">
    Flowchart of Openchallenge Algorithm
  </a>
</p>

<p align="center"> 
  <a href="other/images/Open-Challenge/Algorithm Flowchart Part2.PNG" target="_blank">
    Flowchart of Openchallenge Algorithm
  </a>
</p>

## Obstacle Challenge Navigation System

### Startup from the Parking Lot

The autonomous navigation system employs a directional determination algorithm to establish the optimal path configuration from the initial parking position. The system operates under two distinct navigational modes: Counter-Clockwise (CCW) and Clockwise (CW) trajectories.

#### Directional Determination Algorithm

The navigation direction is determined through comparative analysis of bilateral ultrasonic sensor readings at system initialization. The directional classification follows the mathematical relationship:

```
Direction = {
    CCW,  if d_right < d_left
    CW,   if d_right ≥ d_left
}
```

Where:
- `d_right` = distance measurement from right ultrasonic sensor (mm)
- `d_left` = distance measurement from left ultrasonic sensor (mm)

This comparative threshold analysis ensures optimal path selection based on the immediate environmental constraints surrounding the vehicle's initial position.

---

#### Counter-Clockwise (CCW) Navigation Mode

The operational behavior of the robotic system in CCW mode is demonstrated through visual representation and analysis. The navigation protocol is contingent upon the chromatic identification of the initial pillar encountered, resulting in two distinct operational scenarios based on color detection.

##### Red Pillar Case

<p align="center"> 
 Startup CCW Obstacle-Challenge Algorithm 
</p>

<p align="center"> 
 Startup CCW Obstacle-Challenge Algorithm 
</p>

<p align="center"> 
 Startup CCW Obstacle-Challenge Algorithm 
</p>

<p align="center"> 
 Startup CCW Obstacle-Challenge Algorithm 
</p>

<p align="center"> 
 Startup CCW Obstacle-Challenge Algorithm 
</p>

**The Following is a gif file that explains the Startup CCW Obstacle-Challenge Algorithm (Red Pillar Case):**
<p align="center"> 
 Startup CCW Obstacle-Challenge Algorithm (Red Pillar Case) 
</p>

---
##### Green Pillar Case

<p align="center"> 
 Startup CCW Obstacle-Challenge Algorithm 
</p>

<p align="center"> 
 Startup CCW Obstacle-Challenge Algorithm 
</p>

<p align="center"> 
 Startup CCW Obstacle-Challenge Algorithm 
</p>

<p align="center"> 
 Startup CCW Obstacle-Challenge Algorithm 
</p>

<p align="center"> 
 Startup CCW Obstacle-Challenge Algorithm 
</p>

<p align="center"> 
 Startup CCW Obstacle-Challenge Algorithm 
</p>

<p align="center"> 
 Startup CCW Obstacle-Challenge Algorithm 
</p>

**The Following is a gif file that explains the Startup CCW Obstacle-Challenge Algorithm (Green Pillar Case):**
<p align="center"> 
 Startup CCW Obstacle-Challenge Algorithm (Green Pillar Case) 
</p>

---

#### Clockwise (CW) Navigation Mode

In the CW operational mode, the system demonstrates chromatic independence, whereby the pillar color classification does not influence the navigation algorithm. The operational methodology is illustrated through visual documentation.

<p align="center"> 
 Startup CW Obstacle-Challenge Algorithm 
</p>

<p align="center"> 
 Startup CW Obstacle-Challenge Algorithm 
</p>

<p align="center"> 
 Startup CW Obstacle-Challenge Algorithm 
</p>

<p align="center"> 
 Startup CW Obstacle-Challenge Algorithm 
</p>

**The Following is a gif file that explains the Startup CW Obstacle-Challenge Algorithm:**
<p align="center"> 
 Startup CW Obstacle-Challenge Algorithm 
</p>

---

### Corner Positioning Protocol
Upon completion of the startup initialization sequence, the robotic system transitions to a standardized corner positioning maneuver. This operational phase demonstrates mode independence, whereby the navigation behavior remains uniform regardless of the previously executed directional mode (CCW or CW). The corner approach methodology is implemented as follows:

#### Example Scenario: Post-CCW Red Pillar Transition

<p align="center"> 
 Corner Positioning Protocol 
</p>

<p align="center"> 
 Corner Positioning Protocol 
</p>

<p align="center"> 
 Corner Positioning Protocol 
</p>

**The Following is a gif file that explains the Corner Positioning Protocol:**
<p align="center"> 
 Corner Positioning Protocol 
</p>

### Navigation Through Pillars

#### Overview

The autonomous navigation system implements chromatic pillar detection and directional navigation algorithms to traverse the obstacle course. The robot employs color recognition sensors to identify pillar configurations and executes predefined navigation functions based on the detected color sequence and required turning direction.

#### Function Classification Matrix

The navigation system utilizes eight distinct functions organized according to pillar color combinations and rotational directions:

| First Pillar | Second Pillar | Clockwise (CW) | Counter-Clockwise (CCW) |
|---|---|---|---|
| Red | Red | `red_red_CW` | `red_red_CCW` |
| Red | Green | `red_green_CW` | `red_green_CCW` |
| Green | Red | `green_red_CW` | `green_red_CCW` |
| Green | Green | `green_green_CW` | `green_green_CCW` |

#### Detailed Function Analysis

##### Red-Red Counter-Clockwise Navigation (`red_red_counterclockwise`)

This function implements a sophisticated obstacle avoidance algorithm for traversing two consecutive red pillars in counter-clockwise direction.

**Key Parameters:**
- Initial servo adjustment: `ServoStraight + 35°`
- MPU angular threshold: `mpu_reference + 30°`
- Critical distance threshold: `23 cm`
- Motor speed: `75 PWM units`

**Algorithm Phases:**

1. **Initial Turn Phase:**
   ```
   Δθ = 30° (relative to reference)
   d_critical = 23 cm
   v_motor = 75 PWM
   ```

2. **Obstacle Detection:**
   - Monitors front ultrasonic sensor (`Fast_dist(1)`)
   - Triggers emergency stop if distance < 23 cm

3. **Collision Avoidance Protocol:**
   ```
   if (d_front < 5 cm):
       execute_backward_maneuver()
       t_backward = 750 ms
       v_backward = 40 PWM
   ```

4. **Navigation Completion:**
   - Total execution time: `3400 + 1100×r ms` (where r = collision flag)
   - Final approach distance: `79 cm`

##### Red-Red Clockwise Navigation (`red_red_clockwise`)

Implements adaptive navigation based on initial distance measurements with dynamic angle calculation.

**Adaptive Angular Calculation:**
```
TETA_MPU = 70° - d_initial
where d_initial = Fast_dist(6)
```

**Distance-Based Routing:**

- **Long Distance Route** (`d > 65 cm`):
  - Direct approach with dual sensor monitoring
  - Timeout protection: `1000 ms`

- **Short Distance Route** (`d ≤ 65 cm`):
  - Complex multi-phase navigation:
    ```
    Phase 1: θ₁ = mpu_reference + 1.0 × TETA_MPU
    Phase 2: d_threshold = 77 - 0.2 × TETA_MPU
    Phase 3: θ₂ = mpu_reference + 0.65 × TETA_MPU
    ```

##### Red-Green Clockwise Navigation (`red_green_clockwise`)

Similar base algorithm to red-red clockwise with modified final approach sequence for green pillar interaction.

**Key Modifications:**
- Final turn angle: `-35°` relative to reference
- Green pillar distance threshold: `27 cm`
- Enhanced collision detection for green pillar approach

##### Red-Green Counter-Clockwise Navigation (`red_green_counterclockwise`)

Implements a sequential two-pillar navigation with intermediate positioning.

**Navigation Sequence:**
1. **Red Pillar Phase:**
   - Initial turn: `+30°`
   - Distance threshold: `27 cm`
   - Collision avoidance active

2. **Transition Phase:**
   - Execution time: `2100 + 1350×r ms`
   - Continuous PID control

3. **Green Pillar Phase:**
   - Turn angle: `-35°`
   - Distance threshold: `23 cm`
   - Final positioning accuracy: `±3°`

##### Green-Red Counter-Clockwise Navigation (`green_red_counterclockwise`)

**Adaptive Algorithm with Distance-Based Branching:**

```
if d_initial > 65 cm:
    execute_direct_approach()
else:
    TETA_MPU = 70 - d_initial
    execute_calculated_approach()
```

**Calculated Approach Parameters:**
- Initial servo: `ServoStraight - 45°`
- Angular calculation: `θ = mpu_reference - 1.1 × TETA_MPU`
- Distance threshold: `75 - 0.2 × TETA_MPU`

##### Green-Red Clockwise Navigation (`green_red_clockwise`)

Implements mirror algorithm of green-red counter-clockwise with reversed angular calculations.

**Key Parameters:**
- Initial servo adjustment: `ServoStraight - 50°`
- Angular threshold: `mpu_reference - 30°`
- Execution time: `2100 + 1300×r ms`

##### Green-Green Clockwise Navigation (`green_green_clockwise`)

Simplified navigation for uniform green pillar environment.

**Algorithm Features:**
- Single-phase approach
- Distance threshold: `26.5 cm`
- Execution time: `1300 ms`
- PID function: `cwL_pid()`

##### Green-Green Counter-Clockwise Navigation (`green_green_counterclockwise`)

Most complex function with enhanced angular calculations and servo adjustments.

**Advanced Servo Calculation:**
```
servo_angle = ServoStraight + 35° - 0.002 × d²
```

**Enhanced Angular Calculation:**
```
θ = mpu_reference - 1.25 × TETA_MPU
```

#### Visual Example: Green-Red Counter-Clockwise

The `green_red_counterclockwise` function demonstrates the complete navigation workflow through visual representation of robot movement patterns, sensor readings, and decision points throughout the pillar traversal sequence.

<p align="center"> 
 Green-Red Counter-Clockwise 
</p>

<p align="center"> 
 Green-Red Counter-Clockwise 
</p>

<p align="center"> 
 Green-Red Counter-Clockwise 
</p>

<p align="center"> 
 Green-Red Counter-Clockwise 
</p>

<p align="center"> 
 Green-Red Counter-Clockwise 
</p>

<p align="center"> 
 Green-Red Counter-Clockwise 
</p>

<p align="center"> 
 Green-Red Counter-Clockwise 
</p>

<p align="center"> 
 Green-Red Counter-Clockwise 
</p>

**The Following is a gif file that illustrates Green-Red Counter-Clockwise case:**
<p align="center"> 
 Green-Red Counter-Clockwise 
</p>

#### Parking Lot Proximity Adjustments

**Critical Consideration:** When pillar navigation occurs within the parking lot vicinity, the system requires calibration modifications to the bilateral distance sensor readings. Minor adjustments to the left (`d_left`) and right (`d_right`) ultrasonic sensor parameters provide sufficient compensation for the altered environmental geometry in this operational zone.

---

### Parking in the parking lot

There are two types of parking and it depends on how the robot face the parking lot:

#### Forward Parking (Which we used):

This strategy is used when the robot approaches the parking lot from the front, such that the entrance to the lot is on the right-hand side (although the method can be mirrored for the left).
1.	Approach detection:
-	The robot drives forward while continuously monitoring its right-side sensor (ultrasonic).
-	When the sensor detects a sudden decrease in distance (the robot recognizes the entrance).
2.	Entrance confirmation:
-	To avoid false detection at the wall edge, the robot may move forward a small additional distance after the first detection.
-	At this point, the robot stops and prepares for the parking maneuver.
3.	Parking maneuver :
-	The robot steers right and moves forward into the parking lot.
-	Once the front of the robot clears the outer wall, it begins steering back to the left to align with the lot.
-	Depending on the exact geometry, this can be done in a single smooth curve or in repeated small forward + alignment steps.
4.	Final positioning:
-	When the is fully in the parking it stops the process.

**The Following is a gif file that illustrates our parking algorithm:**
<p align="center"> 
 Parking 
</p>

#### Backward Parking:
This strategy is used when the robot must enter the parking lot in reverse (for example, if its final approach is parallel to the lot). This is often more precise because reversing gives better control of alignment.
1.	Approach detection:
-	The robot drives backward along the lane, using the rear-right sensor to monitor for the parking entrance.
-	When the entrance gap is detected, the robot continues a small extra distance to confirm it has reached the correct spot.
2.	Maneuver Steps:        
-	The robot steers right and reverses into the parking lot entrance.
-	As soon as the back half of the robot clears the first wall, the robot steers left to align itself parallel with the walls.
-	This trajectory is smoother than forward parking

#### Sensors Used for Parking

To ensure accurate and reliable parking, the robot uses a combination of four main sensors. **Ultrasonic sensors** are mounted on the sides and rear to measure distances from the parking lot walls and detect the entrance gap. An **MPU IMU (Inertial Measurement Unit)** provides orientation and heading information, allowing the robot to execute precise turning maneuvers while entering the lot. Additionally, an **infrared (IR) sensor** is installed on a long holder above the chassis, giving the robot a top-down perspective to detect the parking lot boundaries and prevent collisions with the walls. By combining these sensors, the robot can both detect the parking space accurately and control its motion to achieve safe and centered parking.

---

## Pillar Color Detection Methodology

### Overview

The autonomous navigation system employs computer vision techniques to identify and classify pillar configurations within the obstacle course. The detection methodology utilizes HSV color space filtering combined with morphological image processing to achieve robust pillar recognition under varying lighting conditions.

### Color Detection Algorithm

#### HSV Color Space Conversion

The system converts captured RGB frames to HSV (Hue, Saturation, Value) color space to improve color discrimination accuracy:

```
Frame_HSV = RGB2HSV(Frame_RGB)
```

#### Color Range Filtering

Pillar detection employs predefined HSV ranges optimized for the specific pillar colors:

**Red Pillar Detection:**
- Range 1: H(120-179°), S(150-255), V(120-255)
- Range 2: H(130-179°), S(150-255), V(120-255)
- Combined using XOR operation for enhanced red detection

**Green Pillar Detection:**
- Range: H(15-50°), S(15-255), V(50-255)

#### Morphological Processing

Noise reduction and feature enhancement through morphological operations:

1. **Opening Operation**: Removes small noise artifacts
2. **Closing Operation**: Fills gaps within pillar contours
3. **Kernel Size**: 5×5 pixel structuring element

#### Contour Analysis and Feature Extraction

The system extracts pillar characteristics from processed binary masks:

- **Area Calculation**: `A = cv2.contourArea(contour)`
- **Centroid Computation**: `cx = M["m10"] / M["m00"]`
- **Area Thresholds**: Red (200 pixels), Green (300 pixels)

### Pillar Sorting Methodology

#### Primary Sorting Criterion: Area-Based Ranking

Pillars are sorted by contour area in descending order to prioritize the most prominent detections:

```
pillars.sort(key=lambda pillar: pillar['area'], reverse=True)
```

This approach ensures that:
- Larger, closer pillars receive higher priority
- Small noise artifacts are naturally filtered out
- Consistent detection hierarchy is maintained

#### Secondary Sorting: Horizontal Position

For three-pillar scenarios, horizontal position sorting (cx coordinate) enables directional filtering:

```
pillars.sort(key=lambda pillar: pillar['cx'])
```

### Pillar Configuration Classification

The system recognizes four distinct pillar configurations based on detected color combinations:

#### Case 1: Red-Green (RG) Configuration

**Characteristics:**
- First pillar: Red
- Second pillar: Green
- Navigation strategy: Mixed-color approach

<p align="center"> 
RG
RG
</p>

#### Case 2: Green-Red (GR) Configuration

**Characteristics:**
- First pillar: Green
- Second pillar: Red
- Navigation strategy: Reverse mixed-color approach

<p align="center"> 
GR
GR
</p>

#### Case 3: Red-Red (RR) Configuration

**Characteristics:**
- Both pillars: Red
- Uniform color navigation
- Single red pillar automatically becomes RR

<p align="center"> 
RR
RR
</p>

#### Case 4: Green-Green (GG) Configuration

**Characteristics:**
- Both pillars: Green
- Uniform color navigation
- Single green pillar automatically becomes GG

<p align="center"> 
GG
GG
</p>

### Single Pillar Handling Protocol

#### Color Duplication Algorithm

When only one pillar is detected, the system implements automatic color duplication:

```
if detected_pillars_count == 1:
    if pillar_color == 'R':
        configuration = 'RR'
    elif pillar_color == 'G':
        configuration = 'GG'
```
<p align="center"> 
G
G
</p>

<p align="center"> 
R
R
</p>

#### Rationale

This approach ensures:
- **Consistency**: All scenarios result in two-pillar configurations
- **Robustness**: System handles partial occlusion or detection failures
- **Simplification**: Navigation algorithms operate on standardized inputs

### Multi-Pillar Resolution Strategy

#### Three-Pillar Scenario

When three pillars are detected, the system applies directional filtering:

**Counter-Clockwise (CCW) Mode:**
- Remove leftmost pillar (lowest cx value)
- Retain center and right pillars

**Clockwise (CW) Mode:**
- Remove rightmost pillar (highest cx value)
- Retain left and center pillars

#### Two-Pillar Selection

For two-pillar scenarios:
- Select the two largest pillars by area
- Maintain original detection order
- Generate final color sequence string

### Error Handling and Edge Cases

#### No Detection Scenario

When no pillars meet the detection criteria:
- Return 'NN' (No Navigation) code
- Trigger re-detection protocol
- Maintain current navigation state

#### Excessive Detection Filtering

For scenarios with more than three pillars:
- Apply aggressive area-based filtering
- Prioritize largest contours
- Implement spatial clustering if necessary

This methodology ensures robust and consistent pillar detection across varying environmental conditions while maintaining computational efficiency for real-time navigation applications.

# Project Information

---

### Attribution

If you use this project in your work, please cite:
```
RoboPegasus Team. (2025). Autonomous Navigation Robot for WRO Future Engineers 2025. 
GitHub. https://github.com/BaraaLazkani/RoboPegasus_Team_WRO2025
```

## Team Contact

### RoboPegasus Team

**🏫 Institution:** Manara University 
**🌍 Location:** Latakia, Syria 
**📅 Competition Year:** 2025

### Team Members
- **Team Coach:** Obai Ibrahim
- **Member 1:** Baraa Lazkani  
- **Member 2:** Hadi Moalla
- **Member 3:** Hasan Mfleh

**Contact us via: baraa.la2004@gmail.com**

---

## 🙏 Acknowledgments

### Special Thanks
- **World Robot Olympiad** for organizing this inspiring competition
- **Open Source Community** for the tools and libraries that made this possible
- **Our Families** for supporting our robotics journey

### Inspiration
This project was inspired by the challenge of creating truly autonomous vehicles and the educational mission of the WRO Future Engineers category.

---

<p align="center">
  <strong>🚀 Built with passion by RoboPegasus Team | WRO Future Engineers 2025 🚀</strong>
</p>

<p align="center">
  <a href="#top">⬆️ Back to Top</a>
</p>

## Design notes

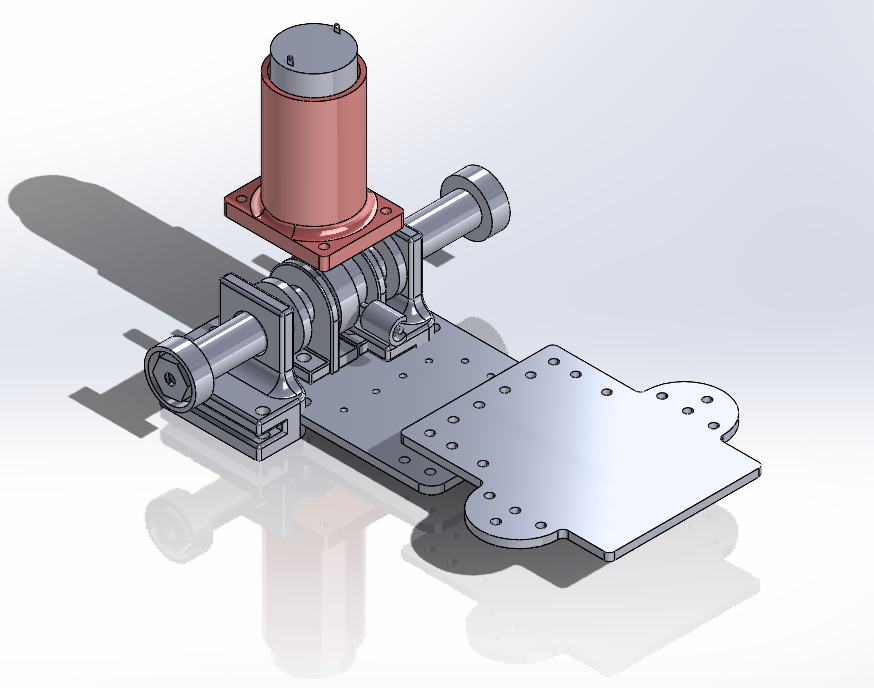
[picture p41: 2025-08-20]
other/images/Our_Differential1.PNG

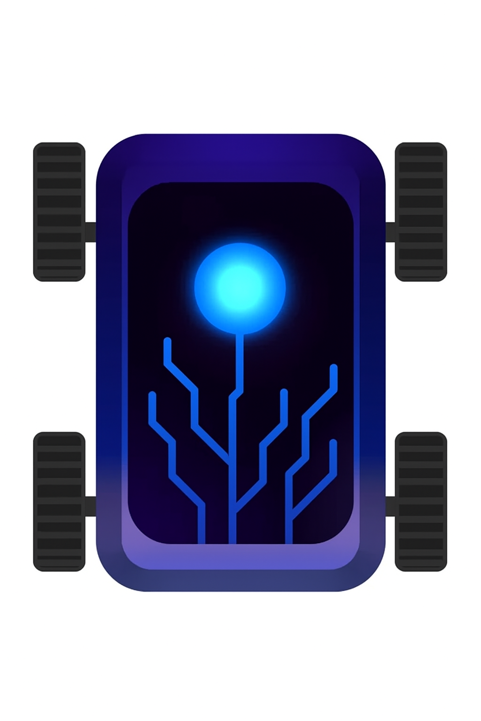
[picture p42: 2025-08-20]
other/images/Beta 2D Robot.png

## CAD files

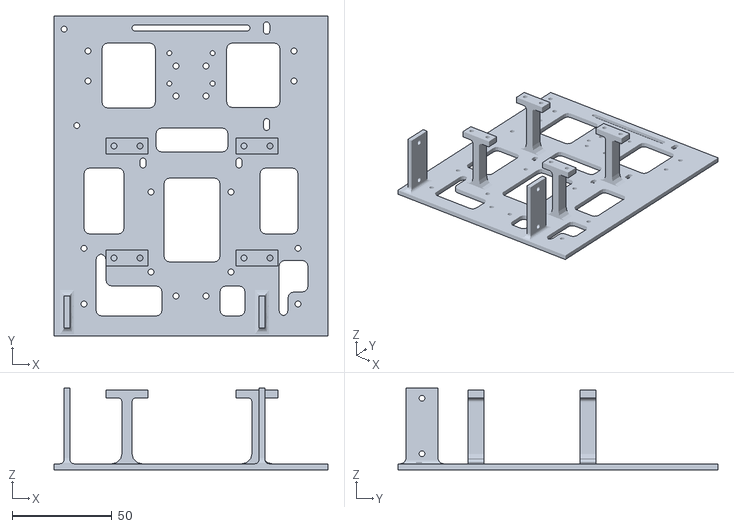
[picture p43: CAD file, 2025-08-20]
models/3D Printed Parts/main_body.STL
137.0 x 160.0 x 40.8

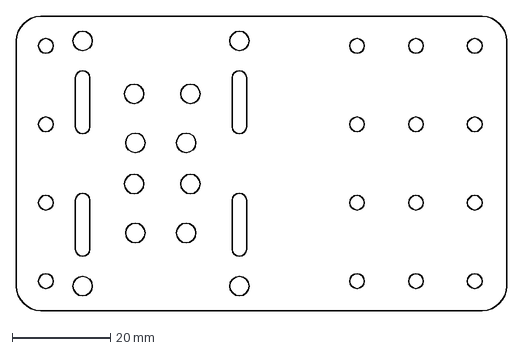
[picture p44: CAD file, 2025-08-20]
models/Laser Cut Parts/Back_Plexi.DXF
100.0 x 60.0 mm

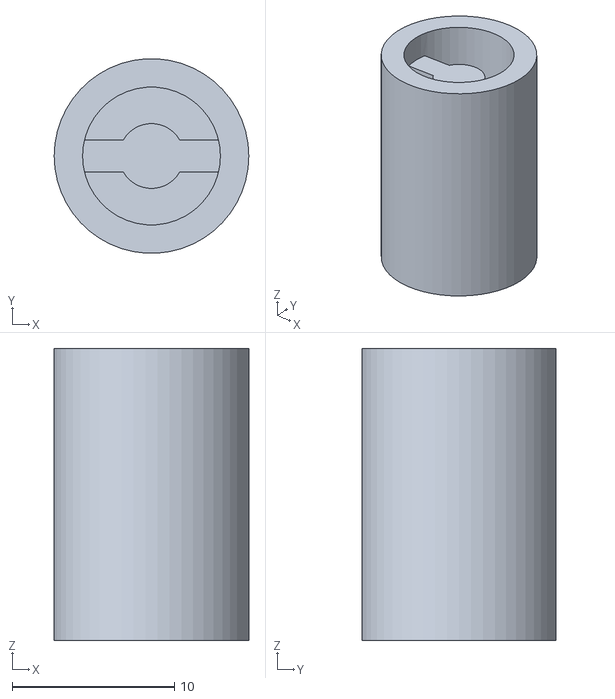
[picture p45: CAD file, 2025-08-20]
models/3D Printed Parts/axis.STL
12.0 x 12.0 x 18.0

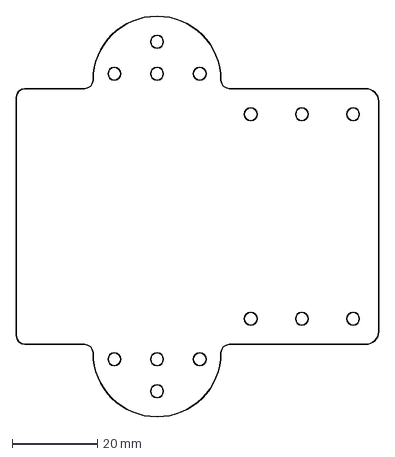
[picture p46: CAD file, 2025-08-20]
models/Laser Cut Parts/Front_Plexi.DXF
85.0 x 94.0 mm

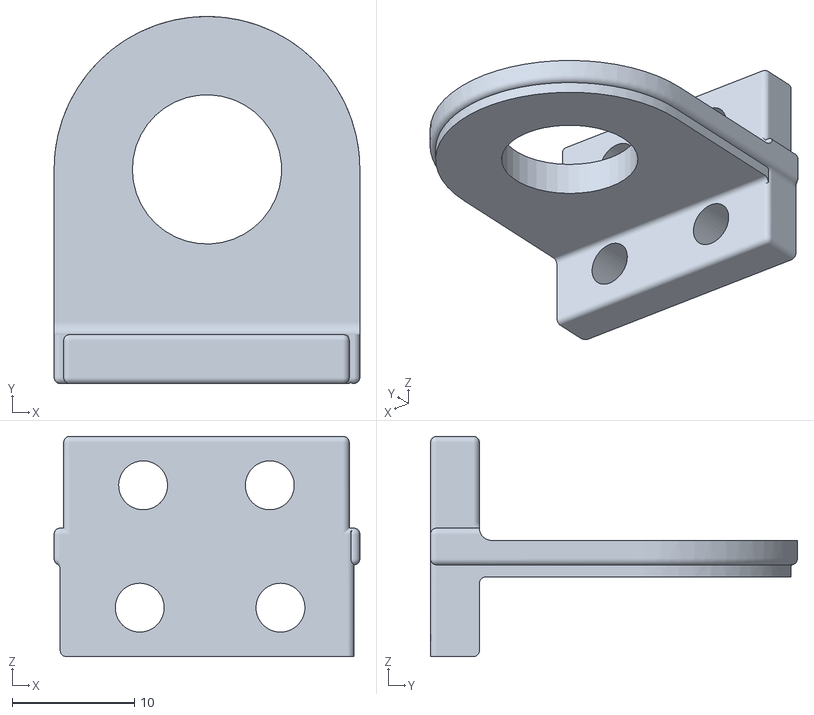
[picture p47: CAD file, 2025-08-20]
models/3D Printed Parts/diff_holder2.STL
25.0 x 30.0 x 18.0

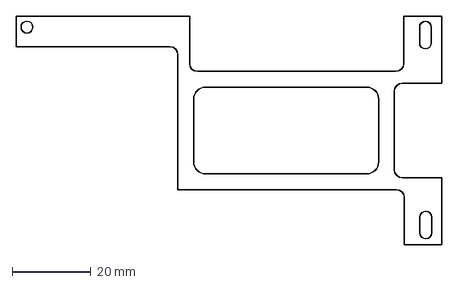
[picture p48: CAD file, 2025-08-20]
models/Laser Cut Parts/DC_to_DC_Buck_Converter_5A_Plexi.DXF
108.0 x 58.0 mm

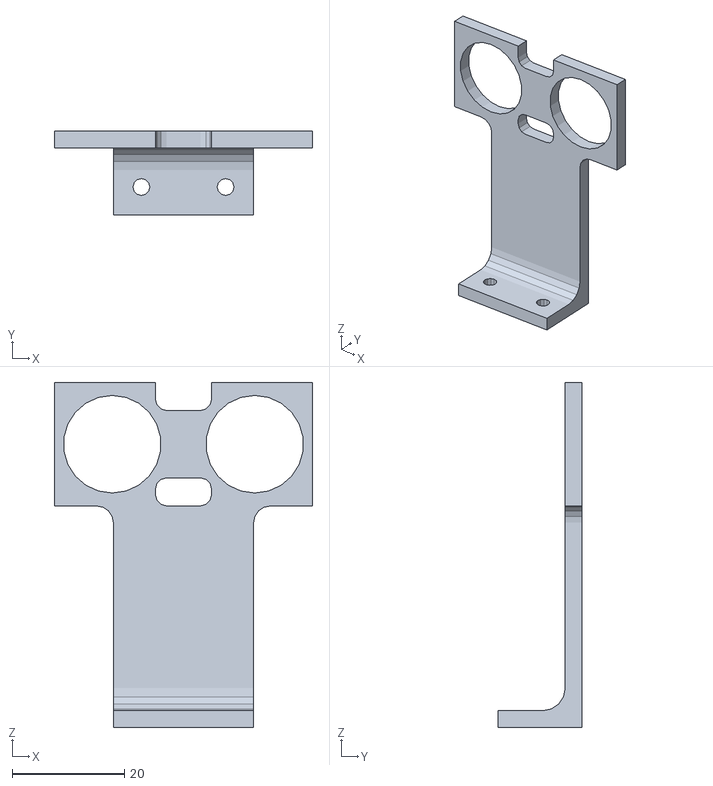
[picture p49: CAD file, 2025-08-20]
models/3D Printed Parts/ultra_holder.STL
46.0 x 15.0 x 61.5

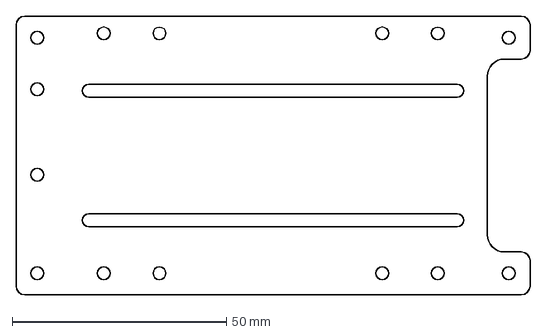
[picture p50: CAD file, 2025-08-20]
models/Laser Cut Parts/PMS_Plexi.DXF
120.0 x 65.0 mm

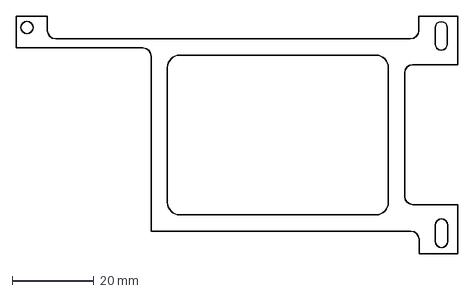
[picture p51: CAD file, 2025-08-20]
models/Laser Cut Parts/DC_to_DC_Buck_Converter_20A_Plexi.DXF
108.0 x 58.0 mm

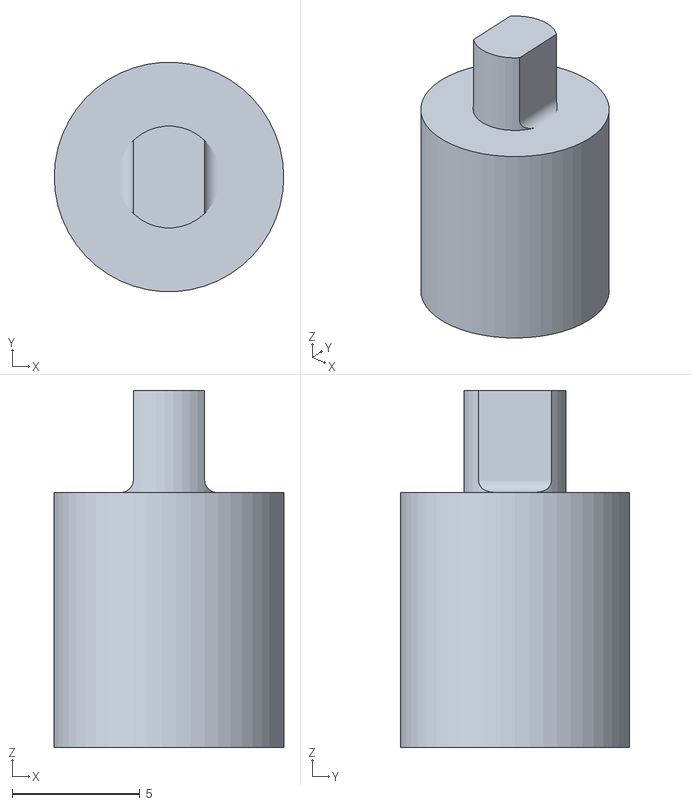
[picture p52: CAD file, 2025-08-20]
models/3D Printed Parts/dc_to_diff.STL
9.00 x 8.98 x 14.0

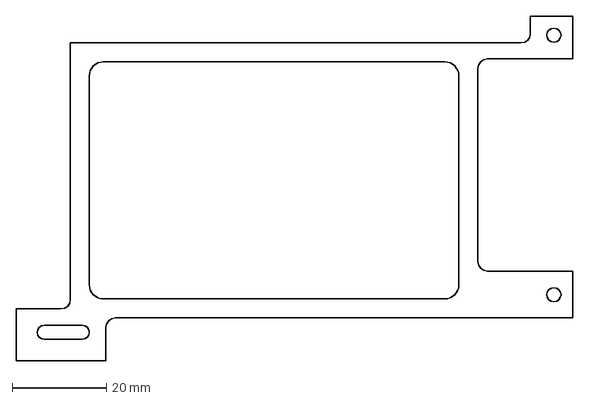
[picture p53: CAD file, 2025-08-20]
models/Laser Cut Parts/RaspberryPi_Plexi.DXF
118.0 x 73.0 mm

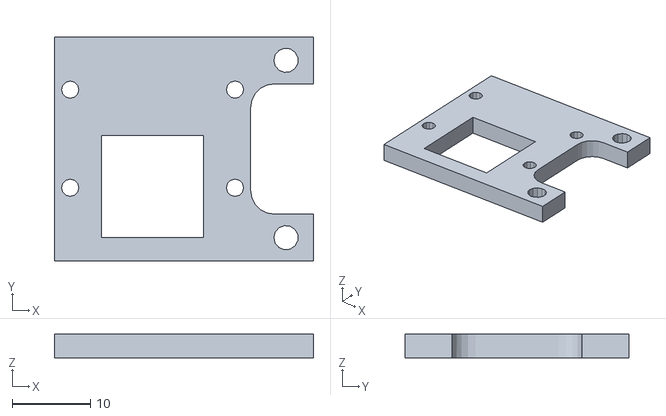
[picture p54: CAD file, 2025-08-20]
models/3D Printed Parts/camera_holder2.STL
33.0 x 28.6 x 3.00

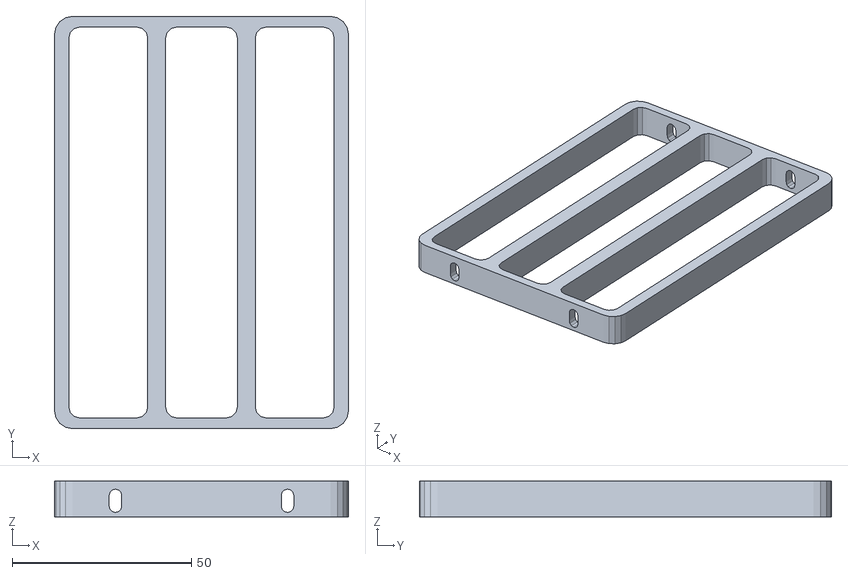
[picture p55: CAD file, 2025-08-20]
models/3D Printed Parts/stander2.STL
82.0 x 115.0 x 10.0

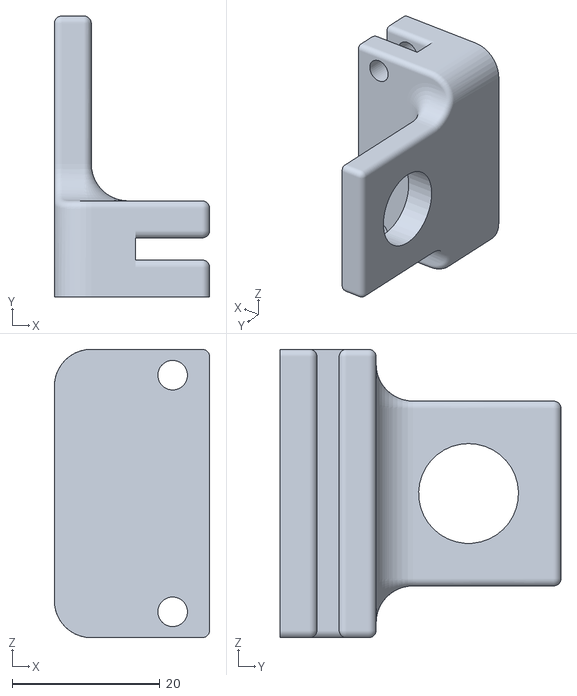
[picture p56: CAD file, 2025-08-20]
models/3D Printed Parts/axis_holder.STL
21.0 x 38.0 x 39.0

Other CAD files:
models/3D Printed Parts/diff_holder1.STL
models/3D Printed Parts/camera_holder1.STL
models/3D Printed Parts/Motor_Holder.STL
models/3D Printed Parts/stander1.STL
models/3D Printed Parts/Hexagonal Rod.STL
models/3D Printed Parts/switch_holder.STL
models/3D Printed Parts/ultra_servo_holder.STL

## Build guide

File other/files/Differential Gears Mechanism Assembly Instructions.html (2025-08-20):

# 🤖 Robot Assembly Guide

Step-by-step instructions for building your precision robotics system

## 📦 Parts Identification

1

Differential Gear Assembly

Complex planetary gear system with internal differential mechanism. Features precision-machined gears for smooth power distribution between output shafts.

Function: Power Distribution

Material: Aluminum Alloy

Key Feature: Planetary Gear System

2

Main Drive Shaft

Precision-turned shaft with integrated mounting flanges and hexagonal drive interface. Designed for high torque transmission.

Function: Power Transmission

Interface: Hexagonal Drive

Bearings: Integrated Flanges

3

Motor Mount Assembly

L-shaped mounting bracket with integrated motor housing. Features precision alignment holes and reinforced construction.

Function: Motor Support

Design: L-Bracket Configuration

Features: Precision Holes

4

Base Plate (Plexi)

Multi-hole mounting plate providing flexible component positioning. Strategic hole pattern allows for various configurations.

Function: Main Chassis

Material: Acrylic (Plexi)

Pattern: Multi-Hole Grid

5

Shaft Bearing Block

Precision bearing housing with mounting tabs. Provides stable rotational support for drive shafts.

Function: Shaft Support

Design: Bearing Housing

Mounting: Bolt-Down Tabs

6

Structural Rail

Aluminum extrusion rail for structural support and component mounting. Provides rigid framework connection.

Function: Structural Support

Profile: T-Slot Extrusion

End Cap: Threaded Insert

7

Motor Housing

Cylindrical motor enclosure with integrated mounting flange. Provides protection and precise motor positioning.

Function: Motor Protection

Material: Anodized Aluminum

Mounting: 4-Bolt Flange

🔧 Tools Required

🔩 Allen Key Set

🔧 Adjustable Wrench

📐 Square/Level

📏 Precision Ruler

## 🔨 Assembly Instructions

1

Prepare the Base Plate

Start by positioning the Base Plate (Plexi) on a clean, flat work surface. This perforated plate will serve as the main chassis for your robot assembly. The strategic hole pattern allows for precise component positioning.

💡 Pro Tip: Orient the base plate so the larger hole clusters are positioned where you'll mount the heavier components (motor and differential assembly).

2

Install Motor Housing

Mount the Motor Housing to the base plate using the 4-bolt flange pattern. Ensure the motor shaft opening is properly aligned with your drive system layout. The red anodized finish indicates the motor mounting side.

⚠️ Critical: Verify motor housing orientation before final tightening. The motor output shaft must align with the differential input.

3

Position Differential Assembly

Install the Differential Gear Assembly in the designated position on the base plate. This complex planetary gear system requires precise alignment with both the motor output and the main drive shaft.

💡 Assembly Tip: The differential housing contains delicate internal gears. Handle with care and avoid applying excessive force during positioning.

4

Install Drive Shaft System

Insert the Main Drive Shaft through the differential assembly. The hexagonal interface end connects to the motor coupling, while the opposite end extends to the output mechanism. Ensure smooth rotation without binding.

5

Add Bearing Support

Mount the Shaft Bearing Block to provide additional support for the drive shaft. This precision bearing housing eliminates shaft deflection and ensures smooth operation under load.

6

Install Motor Mount

Attach the Motor Mount Assembly to the system. This L-shaped bracket provides rigid motor support and precise alignment with the drive train. The integrated housing ensures proper motor positioning.

7

Add Structural Rail

Install the Structural Rail to provide additional framework rigidity. This aluminum extrusion connects key mounting points and prevents flex during operation. The threaded end cap allows for fine positioning adjustments.

8

Final System Integration

Complete the assembly by verifying all connections, checking shaft alignment, and ensuring smooth operation of the differential mechanism. Test rotate all moving parts by hand to confirm proper assembly.

✅ Quality Check: All shafts should rotate smoothly without binding. The differential should operate freely, and motor housing should be rigidly mounted.

🎉

Assembly Complete!

Your precision robotics drive system is now ready for integration with your robot platform. The combined Ackermann steering and differential gear system will provide superior control and maneuverability.

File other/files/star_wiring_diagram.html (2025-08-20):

Star Topology Power Distribution Technique

### Conventional Daisy-Chain Wiring

### Star Topology Wiring

### Advantages of Star Topology Power Distribution

- Current Isolation: Each load's current draw does not affect other loads' supply voltage
- Equal Voltage Distribution: All loads receive the same voltage directly from the source
- Minimized Voltage Drop: No cumulative voltage drops across multiple loads
- Independent Operation: Failure of one load doesn't affect others
- Easy Troubleshooting: Individual circuits can be isolated and tested
- Professional Wire Management: Clean, organized wiring architecture
- Reduced EMI: Lower electromagnetic interference between circuits

### Why Star Topology is Superior for Robotics

In conventional daisy-chain wiring, each subsequent load experiences voltage drop due to wire resistance and current accumulation. This means Load 4 receives significantly less voltage than Load 1, potentially causing performance issues and system instability.

With star topology, each load connects directly to the power source through the central junction, ensuring consistent voltage delivery and eliminating current-induced interference between subsystems. This is particularly critical for robotics applications where sensors and actuators require stable, clean power for optimal performance.

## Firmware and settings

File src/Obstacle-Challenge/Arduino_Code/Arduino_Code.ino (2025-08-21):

/*

  ╔══════════════════════════════════════════════════════════════════════════════════════════════════════════╗
  ║  ██████╗   ██████╗  ██████╗   ██████╗  ██████╗  ███████╗  ██████╗   █████╗  ███████╗ ██╗   ██╗ ███████╗  ║
  ║  ██╔══██╗ ██╔═══██╗ ██╔══██╗ ██╔═══██╗ ██╔══██╗ ██╔════╝ ██╔════╝  ██╔══██╗ ██╔════╝ ██║   ██║ ██╔════╝  ║
  ║  ██████╔╝ ██║   ██║ ██████╔╝ ██║   ██║ ██████╔╝ █████╗   ██║  ███╗ ███████║ ███████╗ ██║   ██║ ███████╗  ║
  ║  ██╔══██╗ ██║   ██║ ██╔══██╗ ██║   ██║ ██╔═══╝  ██╔══╝   ██║   ██║ ██╔══██║ ╚════██║ ██║   ██║ ╚════██║  ║
  ║  ██║  ██║ ╚██████╔╝ ██████╔╝ ╚██████╔╝ ██║      ███████╗ ╚██████╔╝ ██║  ██║ ███████║ ╚██████╔╝ ███████║  ║
  ║  ╚═╝  ╚═╝  ╚═════╝  ╚═════╝   ╚═════╝  ╚═╝      ╚══════╝  ╚═════╝  ╚═╝  ╚═╝ ╚══════╝  ╚═════╝  ╚══════╝  ║
  ╚══════════════════════════════════════════════════════════════════════════════════════════════════════════╝
    Autonomous Robot Navigation System | Arduino Mega Controller
    ─────────────────────────────────────────────────────────────

    🎯 Multi-Sensor Fusion Navigation & Obstacle Avoidance
    🚀 Advanced PID Control with IMU Integration
    🧠 Intelligent Wall Following & Autonomous Turning
    ⚡ Real-time Ultrasonic Array Processing

    Hardware: Arduino Mega, MPU6050, 7x Ultrasonic Sensors, Servo Motors
    Copyright © 2025 RoboPegasus Team | Autonomous Robotics Division

*/

#include <Servo.h>
#include <NewPing.h>
#include "Wire.h"
#include <MPU6050_light.h>
#include <ArduinoQueue.h>

// ============================================================================
// HARDWARE PIN DEFINITIONS
// ============================================================================

// Ultrasonic Sensor Pin Assignments
#define FRONT_TRIG_PIN 25
#define FRONT_ECHO_PIN 24
#define RIGHT_SIDE_TRIG_PIN 53
#define RIGHT_SIDE_ECHO_PIN 52
#define RIGHT_BACK_TRIG_PIN 23
#define RIGHT_BACK_ECHO_PIN 22
#define LEFT_SIDE_TRIG_PIN 12
#define LEFT_SIDE_ECHO_PIN 13
#define LEFT_BACK_TRIG_PIN 51
#define LEFT_BACK_ECHO_PIN 50
#define BACK_RIGHT_TRIG_PIN 29
#define BACK_RIGHT_ECHO_PIN 28
#define BACK_LEFT_TRIG_PIN 49
#define BACK_LEFT_ECHO_PIN 48

// Motor Control Pins
#define RIGHT_MOTOR_PWM 10
#define LEFT_MOTOR_PWM 9

// ============================================================================
// GLOBAL CONSTANTS AND CONFIGURATION
// ============================================================================

// Sensor Configuration
const int ULTRASONIC_MAX_DISTANCE = 300;
const int SENSOR_FILTER_SIZE = 7;
const double SOUND_VELOCITY_CM_US = 0.0343;

// Navigation Parameters
const int STEERING_CENTER_POSITION = 93;
const int LEFT_CENTER_POSITION = 90;
const int RIGHT_CENTER_POSITION = 80;
const int MAX_STEERING_ANGLE = STEERING_CENTER_POSITION + 35;
const int MIN_STEERING_ANGLE = STEERING_CENTER_POSITION - 50;
const int RIGHT_TURN_ANGLE = 40;
const int LEFT_TURN_ANGLE = -55;

// Speed Control Settings
const int NAVIGATION_SPEED = 60;
const int TURNING_SPEED = 60;
const int SAFETY_SPEED = 35;
const int WALL_FOLLOWING_DISTANCE = 15;

// PID Control Parameters
const float MPU_PROPORTIONAL_GAIN = 1.2;
const float MPU_DERIVATIVE_GAIN = 1.0;
const float MAXIMUM_ANGLE_CORRECTION = 0.27;

// ============================================================================
// SENSOR ARRAY DEFINITIONS
// ============================================================================

// Sensor ID Enumeration
enum SensorID {
  FRONT_SENSOR = 0,
  RIGHT_SIDE_SENSOR = 1,
  RIGHT_BACK_SENSOR = 2,
  BACK_RIGHT_SENSOR = 3,
  BACK_LEFT_SIDE_SENSOR = 4,
  LEFT_BACK_SENSOR = 5,
  LEFT_SIDE_SENSOR = 6
};

// Pin Arrays for Sensor Initialization
int ultrasonic_echo_pins[7] = {
  FRONT_ECHO_PIN, RIGHT_SIDE_ECHO_PIN, RIGHT_BACK_ECHO_PIN,
  BACK_RIGHT_ECHO_PIN, BACK_LEFT_ECHO_PIN, LEFT_BACK_ECHO_PIN, LEFT_SIDE_ECHO_PIN
};

int ultrasonic_trigger_pins[7] = {
  FRONT_TRIG_PIN, RIGHT_SIDE_TRIG_PIN, RIGHT_BACK_TRIG_PIN,
  BACK_RIGHT_TRIG_PIN, BACK_LEFT_TRIG_PIN, LEFT_BACK_TRIG_PIN, LEFT_SIDE_TRIG_PIN
};

// ============================================================================
// HARDWARE OBJECTS AND GLOBAL VARIABLES
// ============================================================================

// Servo Motor Objects
Servo steering_servo;
Servo left_gripper_servo;
Servo right_gripper_servo;

// IMU Object
MPU6050 inertial_measurement_unit(Wire);

// Ultrasonic Sensor Array
NewPing ultrasonic_sensors[7] = {
  NewPing(ultrasonic_trigger_pins[0], ultrasonic_echo_pins[0], ULTRASONIC_MAX_DISTANCE),
  NewPing(ultrasonic_trigger_pins[1], ultrasonic_echo_pins[1], ULTRASONIC_MAX_DISTANCE),
  NewPing(ultrasonic_trigger_pins[2], ultrasonic_echo_pins[2], ULTRASONIC_MAX_DISTANCE),
  NewPing(ultrasonic_trigger_pins[3], ultrasonic_echo_pins[3], ULTRASONIC_MAX_DISTANCE),
  NewPing(ultrasonic_trigger_pins[4], ultrasonic_echo_pins[4], ULTRASONIC_MAX_DISTANCE),
  NewPing(ultrasonic_trigger_pins[5], ultrasonic_echo_pins[5], ULTRASONIC_MAX_DISTANCE),
  NewPing(ultrasonic_trigger_pins[6], ultrasonic_echo_pins[6], ULTRASONIC_MAX_DISTANCE)
};

// ============================================================================
// SENSOR FILTERING SYSTEM
// ============================================================================

// Moving Average Filter Queues
ArduinoQueue<double> front_sensor_filter;
ArduinoQueue<double> right_side_filter;
ArduinoQueue<double> right_back_filter;
ArduinoQueue<double> left_side_filter;
ArduinoQueue<double> left_back_filter;
ArduinoQueue<double> back_left_filter;
ArduinoQueue<double> back_right_filter;

// Filtered Sensor Readings
double filtered_front_distance = 0;
double filtered_right_side_distance = 0;
double filtered_right_back_distance = 0;
double filtered_left_side_distance = 0;
double filtered_left_back_distance = 0;
double filtered_back_left_distance = 0;
double filtered_back_right_distance = 0;

// ============================================================================
// NAVIGATION STATE VARIABLES
// ============================================================================

// Turn Execution Flags
bool right_turn_completed = false;
bool left_turn_completed = false;
int total_turn_count = 0;

// Orientation Control
int imu_reference_angle = 0;
double target_steering_angle = 0;
double orientation_error = 0;
double ultrasonic_wall_error = 0;

// ============================================================================
// PILLAR COLORS VARIABLES
// ============================================================================

char colors[8] = {'N', 'N', 'N', 'N', 'N', 'N', 'N', 'N'}; // array to store the pillars
int current_pillar = 0; // pointer for the current pillar
String data = "NN"; // variable to store current two pillars

// Timing Control
long system_delay_timer;

// ============================================================================
// SENSOR DATA ACQUISITION FUNCTIONS
// ============================================================================

/**
   Apply moving average filter to sensor readings for noise reduction
   @param current_reading: Latest sensor measurement
   @param filtered_mean: Reference to filtered value storage
   @param filter_queue: Moving average queue for this sensor
   @return: Filtered sensor value
*/
double apply_sensor_filter(double current_reading, double &filtered_mean, ArduinoQueue<double> &filter_queue) {
  if (filter_queue.isEmpty()) {
    // Initialize filter with current reading
    filtered_mean = current_reading;
    for (int i = 0; i < SENSOR_FILTER_SIZE; i++) {
      filter_queue.enqueue(current_reading);
    }
  } else {
    // Update moving average
    double oldest_value = filter_queue.dequeue();
    filtered_mean -= (oldest_value / SENSOR_FILTER_SIZE);
    filtered_mean += (current_reading / SENSOR_FILTER_SIZE);
    filter_queue.enqueue(current_reading);
  }
  return filtered_mean;
}

/**
   Get filtered distance measurement from front ultrasonic sensor
   @return: Filtered distance in centimeters
*/
double measure_front_distance() {
  double pulse_duration = ultrasonic_sensors[FRONT_SENSOR].ping();
  double raw_distance = (pulse_duration / 2) * SOUND_VELOCITY_CM_US;

  if (raw_distance == 0) raw_distance = ULTRASONIC_MAX_DISTANCE;

  return apply_sensor_filter(raw_distance, filtered_front_distance, front_sensor_filter);
}

/**
   Get filtered distance measurement from right side ultrasonic sensor
   @return: Filtered distance in centimeters
*/
double measure_right_side_distance() {
  double pulse_duration = ultrasonic_sensors[RIGHT_SIDE_SENSOR].ping();
  double raw_distance = (pulse_duration / 2) * SOUND_VELOCITY_CM_US;

  if (raw_distance == 0) raw_distance = ULTRASONIC_MAX_DISTANCE;

  return apply_sensor_filter(raw_distance, filtered_right_side_distance, right_side_filter);
}

/**
   Get filtered distance measurement from left side ultrasonic sensor
   @return: Filtered distance in centimeters
*/
double measure_left_side_distance() {
  double pulse_duration = ultrasonic_sensors[LEFT_SIDE_SENSOR].ping();
  double raw_distance = (pulse_duration / 2) * SOUND_VELOCITY_CM_US;

  if (raw_distance == 0) raw_distance = ULTRASONIC_MAX_DISTANCE;

  return apply_sensor_filter(raw_distance, filtered_left_side_distance, left_side_filter);
}

/**
   Get filtered distance measurement from back left ultrasonic sensor
   @return: Filtered distance in centimeters
*/
double measure_back_left_distance() {
  double pulse_duration = ultrasonic_sensors[BACK_LEFT_SIDE_SENSOR].ping();
  double raw_distance = (pulse_duration / 2) * SOUND_VELOCITY_CM_US;

  if (raw_distance == 0) raw_distance = ULTRASONIC_MAX_DISTANCE;

  return apply_sensor_filter(raw_distance, filtered_back_left_distance, back_left_filter);
}

/**
   Get filtered distance measurement from back right ultrasonic sensor
   @return: Filtered distance in centimeters
*/
double measure_back_right_distance() {
  double pulse_duration = ultrasonic_sensors[BACK_RIGHT_SENSOR].ping();
  double raw_distance = (pulse_duration / 2) * SOUND_VELOCITY_CM_US;

  if (raw_distance == 0) raw_distance = ULTRASONIC_MAX_DISTANCE;

  return apply_sensor_filter(raw_distance, filtered_back_right_distance, back_right_filter);
}

/**
   Get unfiltered distance measurement for quick obstacle detection
   @param sensor_id: ID of the sensor to read
   @return: Raw distance measurement in centimeters
*/
double get_instant_distance(int sensor_id) {
  double pulse_duration = ultrasonic_sensors[sensor_id].ping();
  double distance = (pulse_duration / 2) * SOUND_VELOCITY_CM_US;

  if (distance == 0) distance = ULTRASONIC_MAX_DISTANCE;

  return distance;
}

/**
   Reset all sensor filters to clear accumulated data
*/
void reset_sensor_filters() {
  for (int i = 0; i < SENSOR_FILTER_SIZE; i++) {
    if (!front_sensor_filter.isEmpty()) front_sensor_filter.dequeue();
    if (!right_side_filter.isEmpty()) right_side_filter.dequeue();
    if (!right_back_filter.isEmpty()) right_back_filter.dequeue();
    if (!left_side_filter.isEmpty()) left_side_filter.dequeue();
    if (!left_back_filter.isEmpty()) left_back_filter.dequeue();
    if (!back_left_filter.isEmpty()) back_left_filter.dequeue();
    if (!back_right_filter.isEmpty()) back_right_filter.dequeue();
  }
}

// ============================================================================
// MOTOR CONTROL FUNCTIONS
// ============================================================================

/**
   Drive robot forward at specified speed
   @param speed_percentage: Motor speed as percentage (0-100)
*/
void drive_forward(int speed_percentage) {
  int pwm_value = speed_percentage * 254 / 100;
  analogWrite(LEFT_MOTOR_PWM, 0);
  analogWrite(RIGHT_MOTOR_PWM, pwm_value);
}

/**
   Drive robot backward at specified speed
   @param speed_percentage: Motor speed as percentage (0-100)
*/
void drive_backward(int speed_percentage) {
  int pwm_value = speed_percentage * 254 / 100;
  analogWrite(RIGHT_MOTOR_PWM, 0);
  analogWrite(LEFT_MOTOR_PWM, pwm_value);
}

/**
   Stop all motor movement
*/
void stop_motors() {
  analogWrite(RIGHT_MOTOR_PWM, 0);
  analogWrite(LEFT_MOTOR_PWM, 0);
}

// ============================================================================
// TIMING AND DELAY FUNCTIONS
// ============================================================================

/**
   Non-blocking delay that maintains IMU updates
   @param delay_milliseconds: Duration to delay in milliseconds
*/
void maintain_imu_during_delay(int delay_milliseconds) {
  system_delay_timer = millis();
  while (millis() - system_delay_timer < delay_milliseconds) {
    inertial_measurement_unit.update();
  }
}

// ============================================================================
// PID CONTROL FUNCTIONS
// ============================================================================

/**
   PID control for maintaining orientation during backward movement
*/
void backward_orientation_control() {
  orientation_error = inertial_measurement_unit.getAngleZ() - imu_reference_angle;
  target_steering_angle = STEERING_CENTER_POSITION + (MPU_PROPORTIONAL_GAIN * orientation_error);

  // Apply steering limits
  if (target_steering_angle > MAX_STEERING_ANGLE) target_steering_angle = MAX_STEERING_ANGLE;
  if (target_steering_angle < MIN_STEERING_ANGLE) target_steering_angle = MIN_STEERING_ANGLE;

  steering_servo.write(target_steering_angle);
}

/**
   PID control for maintaining orientation during forward movement
*/
void forward_orientation_control() {
  orientation_error = inertial_measurement_unit.getAngleZ() - imu_reference_angle;
  target_steering_angle = STEERING_CENTER_POSITION - (MPU_PROPORTIONAL_GAIN * orientation_error);

  // Apply steering limits
  if (target_steering_angle > MAX_STEERING_ANGLE) target_steering_angle = MAX_STEERING_ANGLE;
  if (target_steering_angle < MIN_STEERING_ANGLE) target_steering_angle = MIN_STEERING_ANGLE;

  steering_servo.write(target_steering_angle);
}

/**
   PID control for maintaining orientations of servos that holds ultrasonic sensors during movement
*/

void servo_ultra_pid() {
  float error = inertial_measurement_unit.getAngleZ() - imu_reference_angle;
  delay(10);
  if (error > 80) {
    left_gripper_servo.write(LEFT_CENTER_POSITION - 80);
    right_gripper_servo.write(RIGHT_CENTER_POSITION - 80);
  }
  else if (error < -80) {
    left_gripper_servo.write(LEFT_CENTER_POSITION + 80);
    right_gripper_servo.write(RIGHT_CENTER_POSITION + 80);
  }
  else {
    left_gripper_servo.write(LEFT_CENTER_POSITION - error);
    right_gripper_servo.write(RIGHT_CENTER_POSITION - error);
  }
}
/**
   Wall following control for left side obstacles
   @param wall_distance: Current distance to left wall
*/
void maintain_left_wall_distance(double wall_distance) {
  if (wall_distance < WALL_FOLLOWING_DISTANCE) {
    ultrasonic_wall_error = WALL_FOLLOWING_DISTANCE - wall_distance;
    steering_servo.write(STEERING_CENTER_POSITION + 1.2 * ultrasonic_wall_error);
    maintain_imu_during_delay(10);
  }
}

/**
   Wall following control for right side obstacles
   @param wall_distance: Current distance to right wall
*/
void maintain_right_wall_distance(double wall_distance) {
  if (wall_distance < WALL_FOLLOWING_DISTANCE) {
    ultrasonic_wall_error = WALL_FOLLOWING_DISTANCE - wall_distance;
    steering_servo.write(STEERING_CENTER_POSITION - 1.2 * ultrasonic_wall_error);
    maintain_imu_during_delay(10);
  }
}

// ============================================================================
// NAVIGATION MANEUVER FUNCTIONS
// ============================================================================

/**
   Execute 90-degree right turn maneuver
*/
void execute_right_turn() {
  // Prevent multiple consecutive turns
  if (right_turn_completed && total_turn_count != 0) return;

  maintain_imu_during_delay(30);

  // Handle front obstacle during turn initiation
  if (get_instant_distance(FRONT_SENSOR) < 35) {
    stop_motors();
    maintain_imu_during_delay(30);

    // Back away from obstacle
    while (get_instant_distance(FRONT_SENSOR) < 40) {
      drive_backward(SAFETY_SPEED);
      backward_orientation_control();
      maintain_imu_during_delay(30);
    }

    stop_motors();
    maintain_imu_during_delay(20);
    drive_forward(SAFETY_SPEED);
    maintain_imu_during_delay(250);
  }

  // Execute turning sequence
  steering_servo.write(STEERING_CENTER_POSITION + RIGHT_TURN_ANGLE);
  drive_forward(TURNING_SPEED);
  inertial_measurement_unit.update();

  // Turn until 70-degree rotation achieved
  while (inertial_measurement_unit.getAngleZ() < imu_reference_angle + 70) {
    inertial_measurement_unit.update();
  }

  // Update reference angle and complete turn
  imu_reference_angle += 90;
  stop_motors();
  maintain_imu_during_delay(50);
  steering_servo.write(STEERING_CENTER_POSITION);
  maintain_imu_during_delay(50);

  // Resume navigation
  drive_forward(NAVIGATION_SPEED);
  inertial_measurement_unit.update();
  forward_orientation_control();
  reset_sensor_filters();

  right_turn_completed = true;
  total_turn_count++;
  maintain_imu_during_delay(30);

  // Navigate until clear of turn area
  while (measure_back_left_distance() < 110 && measure_back_right_distance() < 110) {
    maintain_imu_during_delay(30);
    maintain_right_wall_distance(measure_right_side_distance());
    maintain_left_wall_distance(measure_left_side_distance());
    maintain_imu_during_delay(30);

    if (measure_right_side_distance() > WALL_FOLLOWING_DISTANCE &&
        measure_left_side_distance() > WALL_FOLLOWING_DISTANCE) {
      forward_orientation_control();
    }
  }
}

/**
   Execute 90-degree left turn maneuver
*/
void execute_left_turn() {
  // Prevent multiple consecutive turns
  if (left_turn_completed && total_turn_count != 0) return;

  maintain_imu_during_delay(30);

  // Handle front obstacle during turn initiation
  if (get_instant_distance(FRONT_SENSOR) < 35) {
    stop_motors();
    maintain_imu_during_delay(30);

    // Back away from obstacle
    while (get_instant_distance(FRONT_SENSOR) < 40) {
      drive_backward(SAFETY_SPEED);
      backward_orientation_control();
      maintain_imu_during_delay(30);
    }

    stop_motors();
    maintain_imu_during_delay(20);
    drive_forward(SAFETY_SPEED);
    maintain_imu_during_delay(250);
  }

  // Execute turning sequence
  steering_servo.write(STEERING_CENTER_POSITION + LEFT_TURN_ANGLE);
  drive_forward(TURNING_SPEED);
  inertial_measurement_unit.update();

  // Turn until 70-degree rotation achieved
  while (inertial_measurement_unit.getAngleZ() > imu_reference_angle - 70) {
    inertial_measurement_unit.update();
  }

  // Update reference angle and complete turn
  imu_reference_angle -= 90;
  stop_motors();
  maintain_imu_during_delay(50);
  steering_servo.write(STEERING_CENTER_POSITION);
  maintain_imu_during_delay(50);

  // Resume navigation
  drive_forward(NAVIGATION_SPEED);
  inertial_measurement_unit.update();
  forward_orientation_control();
  reset_sensor_filters();

  left_turn_completed = true;
  total_turn_count++;
  maintain_imu_during_delay(30);

  // Navigate until clear of turn area
  while (measure_back_left_distance() < 110 && measure_back_right_distance() < 110) {
    maintain_imu_during_delay(30);
    maintain_right_wall_distance(measure_right_side_distance());
    maintain_left_wall_distance(measure_left_side_distance());
    maintain_imu_during_delay(30);

    if (measure_right_side_distance() > WALL_FOLLOWING_DISTANCE &&
        measure_left_side_distance() > WALL_FOLLOWING_DISTANCE) {
      forward_orientation_control();
    }
  }
}



// ============================================================================
// READING PILLARS' COLORS FUNCTION
// ============================================================================

void READ_PILLAR_COLOR() {
  stop_motors(); // stop the motor so the camera can take a clear frame
  delay(3000);
  if (Serial.available() > 0) {
    data = Serial.readStringUntil('#'); // take the data recived from raspberry pi through Serial connection
    Serial.println(data);
    // Store the data in the pillar colors array
    colors[current_pillar] = data[0];
    colors[current_pillar + 1] = data[1];
  }

}
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
void loop() {
  // Start the round and determine the driving direction
  if (get_instant_distance(RIGHT_SIDE_SENSOR) < get_instant_distance(LEFT_SIDE_SENSOR))
  {
    Serial.println("CCW");
    left_turn_completed = true;
    startup_ccw();
  }
  else
  {
    Serial.println("CW");
    right_turn_completed = true ;
    startup_cw();
  }


  for (int sec_num = 0; sec_num < 10; sec_num++) // pass all sections except the starting section and the ending section
  {
    if (sec_num < 4) // if it is the first lap, take color data from camera and store them in the array
    {
      READ_PILLAR_COLOR();
    }
    // pass the two pillars in the section depending on their colors if there is one pillar, it will be duplicated
    if (colors[current_pillar] == 'R') pass_red_pillar();
    else if (colors[current_pillar] == 'G') pass_green_pillar();
    current_pillar = (current_pillar + 1) % 8;

    if (colors[current_pillar] == 'R') pass_red_pillar();
    else if (colors[current_pillar] == 'G') pass_green_pillar();
    current_pillar = (current_pillar + 1) % 8;

    // Turn to the next section
    if (right_turn_completed) execute_right_turn();
    else if (left_turn_completed) execute_left_turn();

  }

  // park the robot

  if (right_turn_completed) PARKING_CW();
  else if (left_turn_completed) PARKING_CCW();

}

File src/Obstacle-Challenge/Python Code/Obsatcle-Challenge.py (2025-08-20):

"""

╔══════════════════════════════════════════════════════════════════════════════════════════════════════════╗
║  ██████╗   ██████╗  ██████╗   ██████╗  ██████╗  ███████╗  ██████╗   █████╗  ███████╗ ██╗   ██╗ ███████╗  ║
║  ██╔══██╗ ██╔═══██╗ ██╔══██╗ ██╔═══██╗ ██╔══██╗ ██╔════╝ ██╔════╝  ██╔══██╗ ██╔════╝ ██║   ██║ ██╔════╝  ║
║  ██████╔╝ ██║   ██║ ██████╔╝ ██║   ██║ ██████╔╝ █████╗   ██║  ███╗ ███████║ ███████╗ ██║   ██║ ███████╗  ║
║  ██╔══██╗ ██║   ██║ ██╔══██╗ ██║   ██║ ██╔═══╝  ██╔══╝   ██║   ██║ ██╔══██║ ╚════██║ ██║   ██║ ╚════██║  ║
║  ██║  ██║ ╚██████╔╝ ██████╔╝ ╚██████╔╝ ██║      ███████╗ ╚██████╔╝ ██║  ██║ ███████║ ╚██████╔╝ ███████║  ║
║  ╚═╝  ╚═╝  ╚═════╝  ╚═════╝   ╚═════╝  ╚═╝      ╚══════╝  ╚═════╝  ╚═╝  ╚═╝ ╚══════╝  ╚═════╝  ╚══════╝  ║
╚══════════════════════════════════════════════════════════════════════════════════════════════════════════╝                                                                                              
   Autonomous Robot Vision System | Pillar Detection & Navigation
   ──────────────────────────────────────────────────────────────
    
    🎯 Advanced Computer Vision for Obstacle Course Navigation
    🚀 Real-time HSV Color Classification & Morphological Processing
    🧠 Intelligent Pillar Configuration Analysis
    ⚡ High-Performance Arduino Communication Interface
    
    Copyright © 2025 RoboPegasus Team | Autonomous Robotics Division

"""    
import serial
import numpy as np
import time
from picamera2 import Picamera2
import cv2 as cv2

# Minimum area thresholds for pillar detection
RED_PILLAR_MIN_AREA = 1700
GREEN_PILLAR_MIN_AREA = 2100

# Global variables for navigation state
navigation_mode = None
initial_pillar_detected = False

def initialize_camera_system():
    """
    Configure and initialize the camera with optimized settings for pillar detection.
    Returns configured camera instance.
    """
    cam = Picamera2()
    camera_config = cam.create_preview_configuration()
    camera_config['main']['format'] = 'RGB888'
    cam.configure(camera_config)
    cam.start()
    cam.set_controls({"AfMode": 1, "LensPosition": 425, "AwbEnable": False})
    return cam

def establish_arduino_connection(port_name='/dev/ttyACM0', baud_rate=115200):
    """
    Establish serial communication with Arduino controller.
    Sends initialization signal and waits for confirmation.
    """
    arduino_link = serial.Serial(port_name, baud_rate, timeout=1)
    arduino_link.flush()
    time.sleep(3.5)
    arduino_link.write("S#".encode('ascii'))
    print("Setup response:", arduino_link.readline().decode().strip())
    return arduino_link

def generate_corner_exclusion_mask(frame_dimensions, exclusion_size=(50, 50)):
    """
    Create a mask to exclude corner regions from pillar detection.
    This prevents false detections from corner artifacts.
    """
    height, width, _ = frame_dimensions
    mask = np.ones((height, width), dtype=np.uint8) * 255
    
    # Exclude top-left corner
    mask[0:exclusion_size[1], 0:exclusion_size[0]] = 0
    
    # Exclude top-right corner  
    x_right = width - exclusion_size[0]
    mask[0:exclusion_size[1], x_right:width] = 0
    
    return mask

def transmit_pillar_information(arduino_connection, pillar_data):
    """
    Send pillar detection results to Arduino controller.
    Appends termination character and handles response.
    """
    message = pillar_data + '#'
    arduino_connection.write(message.encode('ascii'))
    time.sleep(0.1)
    print(arduino_connection.readline())

def extract_pillar_features(color_mask, area_threshold, pillar_type):
    """
    Extract pillar features from color-filtered mask.
    Returns list of detected pillars with their properties.
    """
    # Apply morphological operations to reduce noise
    morphology_kernel = np.ones((5, 5), np.uint8)
    filtered_mask = cv2.morphologyEx(color_mask, cv2.MORPH_OPEN, morphology_kernel)
    filtered_mask = cv2.morphologyEx(filtered_mask, cv2.MORPH_CLOSE, morphology_kernel)

    # Find contours in the processed mask
    contour_list, _ = cv2.findContours(filtered_mask, cv2.RETR_EXTERNAL, cv2.CHAIN_APPROX_SIMPLE)
    
    pillar_objects = []
    for contour in contour_list:
        contour_area = cv2.contourArea(contour)
        
        if contour_area > area_threshold:
            # Calculate centroid coordinates
            moments = cv2.moments(contour)         
            center_x = int(moments["m10"] / moments["m00"])
            
            pillar_objects.append({
                'color': pillar_type,
                'cx': center_x,
                'area': contour_area
            })
    
    return pillar_objects

def process_color_detection(frame_data, red_range_1, red_range_2, green_range):
    """
    Apply color filtering to detect red and green pillars in the frame.
    Returns detected pillar objects and visualization masks.
    """
    hsv_converted = cv2.cvtColor(frame_data, cv2.COLOR_RGB2HSV)
    
    # Create color masks for red and green pillars
    red_mask_lower = cv2.inRange(hsv_converted, *red_range_1)
    red_mask_upper = cv2.inRange(hsv_converted, *red_range_2)
    red_combined_mask = cv2.bitwise_xor(red_mask_lower, red_mask_upper)
    green_mask = cv2.inRange(hsv_converted, *green_range)

    # Extract pillar features from masks
    red_pillars = extract_pillar_features(red_combined_mask, min_area=200, pillar_type='R')
    green_pillars = extract_pillar_features(green_mask, min_area=300, pillar_type='G')
    
    return red_pillars, green_pillars, red_combined_mask, green_mask
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

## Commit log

2025-08-20 3D Models
    [Back_Plexi.DXF, DC_to_DC_Buck_Converter_20A_Plexi.DXF, DC_to_DC_Buck_Converter_5A_Plexi.DXF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]
2025-08-20 Circuits Diagram of the robot and the PMS
    [Full Schematic Circuit of the Robot.fzz]
2025-08-20 Codes
    Open-Challenge Arduino Code
    Obstacle-Challenge Python Code
